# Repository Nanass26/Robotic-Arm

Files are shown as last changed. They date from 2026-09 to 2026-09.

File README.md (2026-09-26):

# ORION-6 — bras robotique 6 axes imprimé en 3D, avec son logiciel ORION Studio

<p align="center">
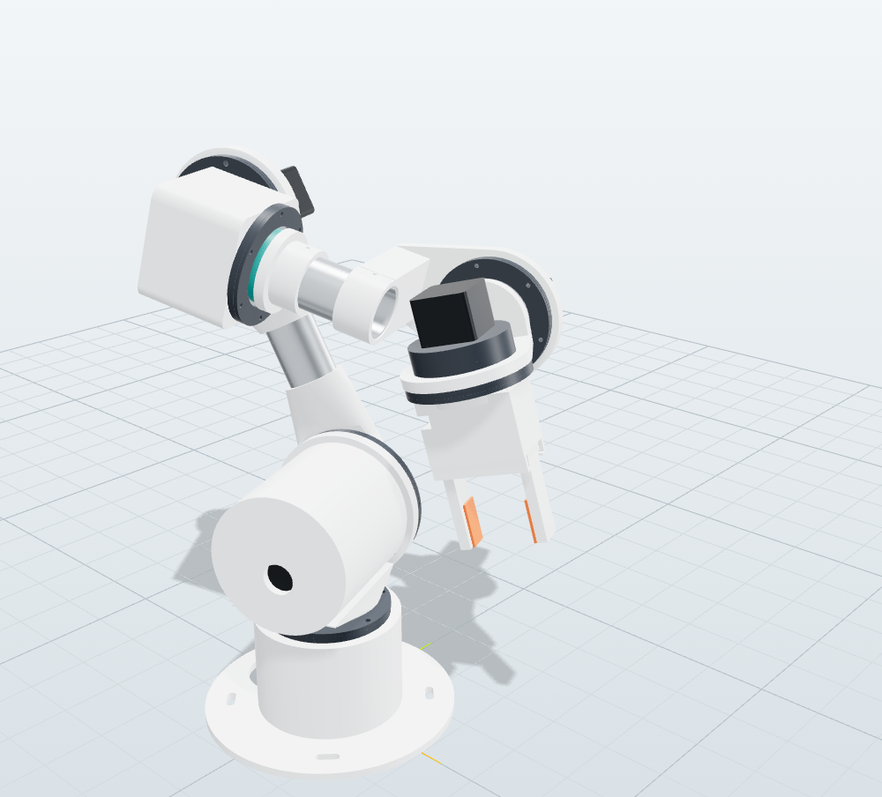
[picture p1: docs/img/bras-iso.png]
Rendu 3D du bras ORION-6 : socle, épaule, bras en tube aluminium, coude, poignet et pince
  
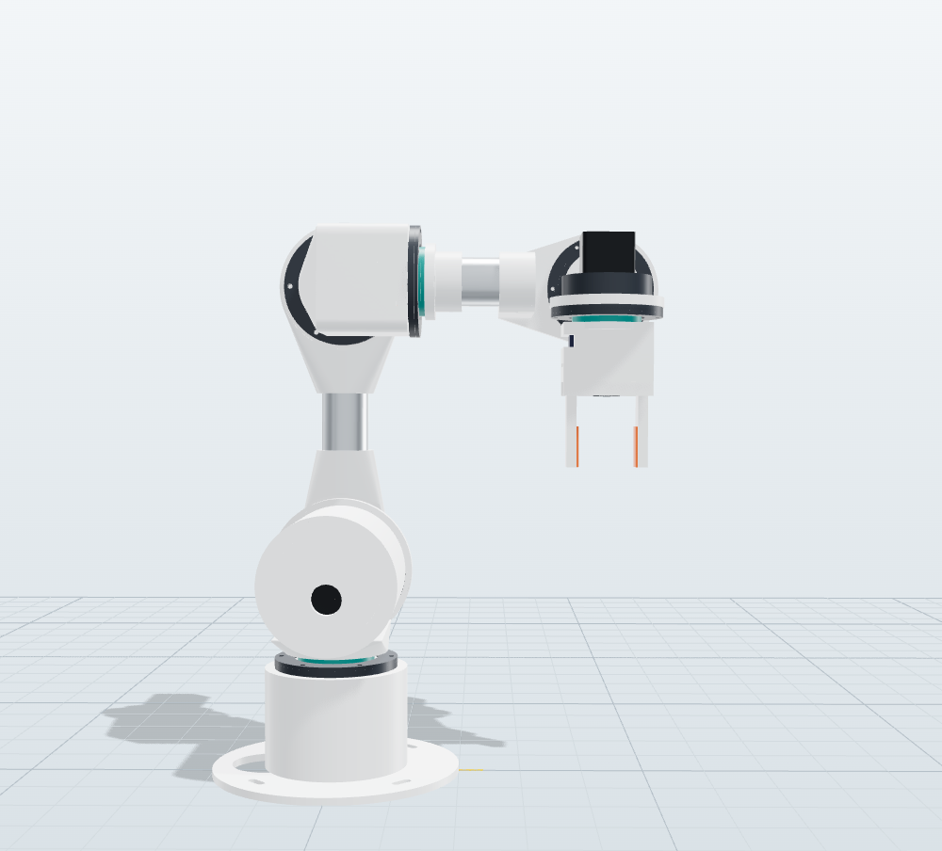
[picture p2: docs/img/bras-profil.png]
Vue de profil du bras ORION-6 en pose Home
  
</p>

**ORION-6** est un bras robotique 6 axes à imprimer en 3D, pensé comme un bras « de laboratoire ». Le dépôt contient tout
le nécessaire :

- **ORION Studio**, un logiciel de simulation et de pilotage (navigateur, hors ligne) : vue 3D, pilotage articulaire et
  cartésien, programmes, assistant en langage naturel, analyse et courbes. **Tous les paramètres** du robot y sont réglables
  en direct : géométrie, masses, moteurs, réducteurs, gains PID et **mode MIT**, trajectoires, sécurité, brochage.
- La **CAO paramétrique** et les **37 fichiers STL** prêts à imprimer. Les réducteurs cycloïdaux sont imprimés, la pince
  est à crémaillère. Le dépôt fournit aussi la nomenclature chiffrée et des contrôles automatiques : interférences,
  débattements, taille du plateau.
- Deux **firmwares Teensy 4.1** testés :
  - le contrôleur **pas-à-pas** de la version MAKER ;
  - le **pont CAN « mode MIT »** de la version PRO, pour moteurs brushless QDD de type Damiao DM4340/DM4310.
- La **documentation en français** : théorie, réglages, impression, câblage, assemblage, calibration, protocole et
  dépannage.

> ⚠️ **Prototype non validé physiquement.** La conception a été vérifiée par calcul et simulation : cinématique, dynamique,
> dimensionnement, engrènement des cycloïdes, interférences CAO et tests du firmware sur PC. Aucun exemplaire n’a encore été
> imprimé ni assemblé. Commencez par le **test de tolérances** (`hardware/stl/tolerance-test.stl`) et un module réducteur
> seul. Un bras motorisé peut blesser : prévoyez un **arrêt d’urgence qui coupe la puissance**, voir
> [docs/09-electronique.md](docs/09-electronique.md).

## Aperçu d’ORION Studio

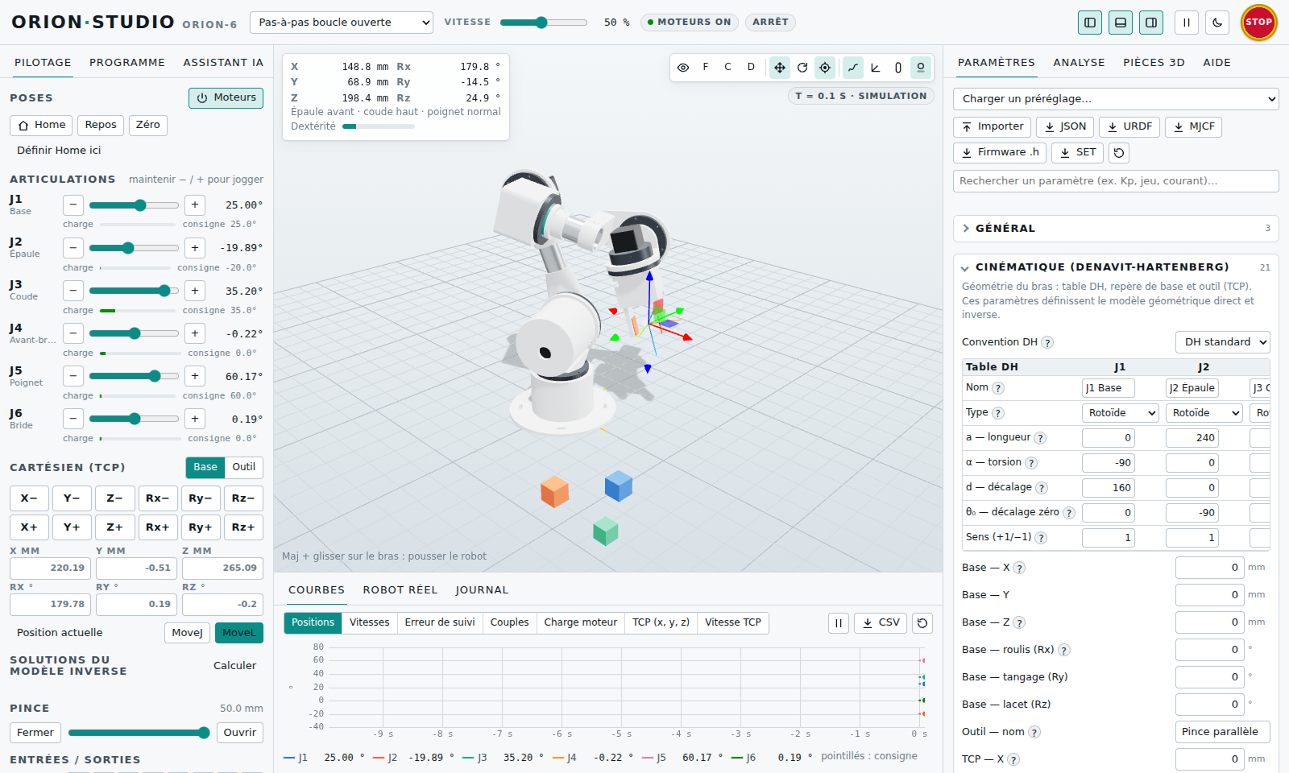
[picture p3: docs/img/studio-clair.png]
ORION Studio : pilotage à gauche, vue 3D au centre, paramètres à droite, courbes en bas


| Programme + courbes | Analyse (dimensionnement, espace de travail) | Thème sombre |
|---|---|---|
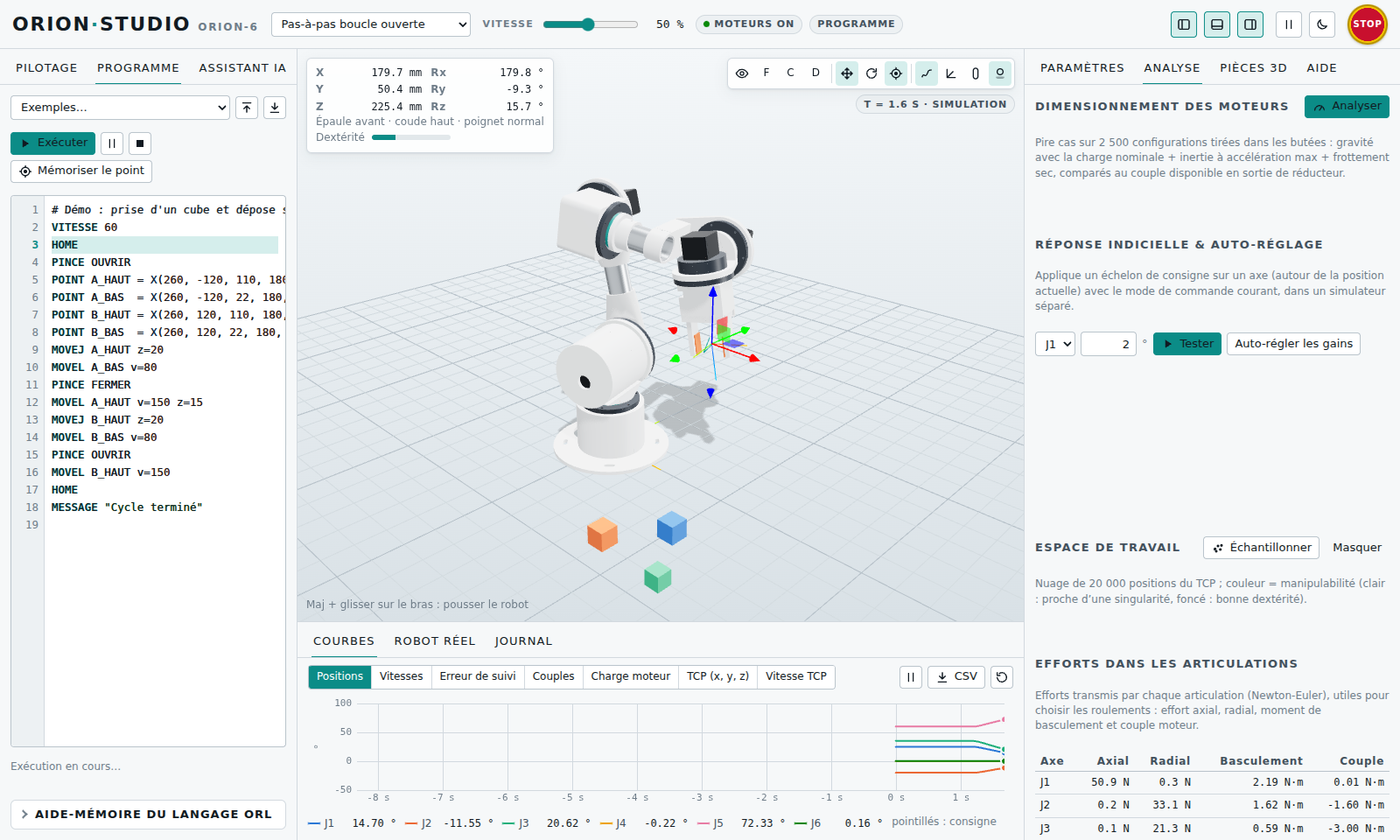
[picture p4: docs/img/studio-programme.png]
Éditeur de programme ORL en cours d’exécution
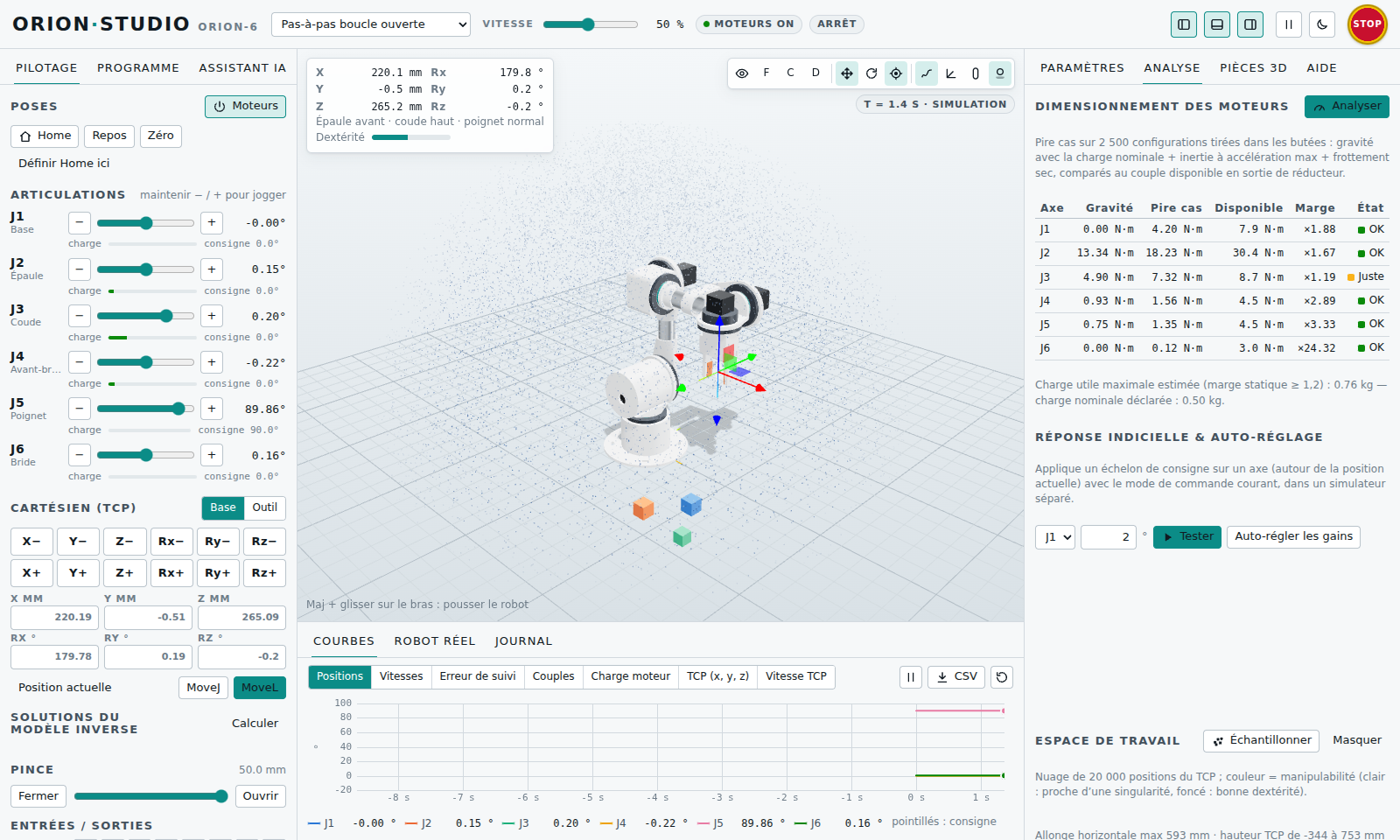
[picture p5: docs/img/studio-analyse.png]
Tableau de dimensionnement des moteurs et nuage de l’espace de travail
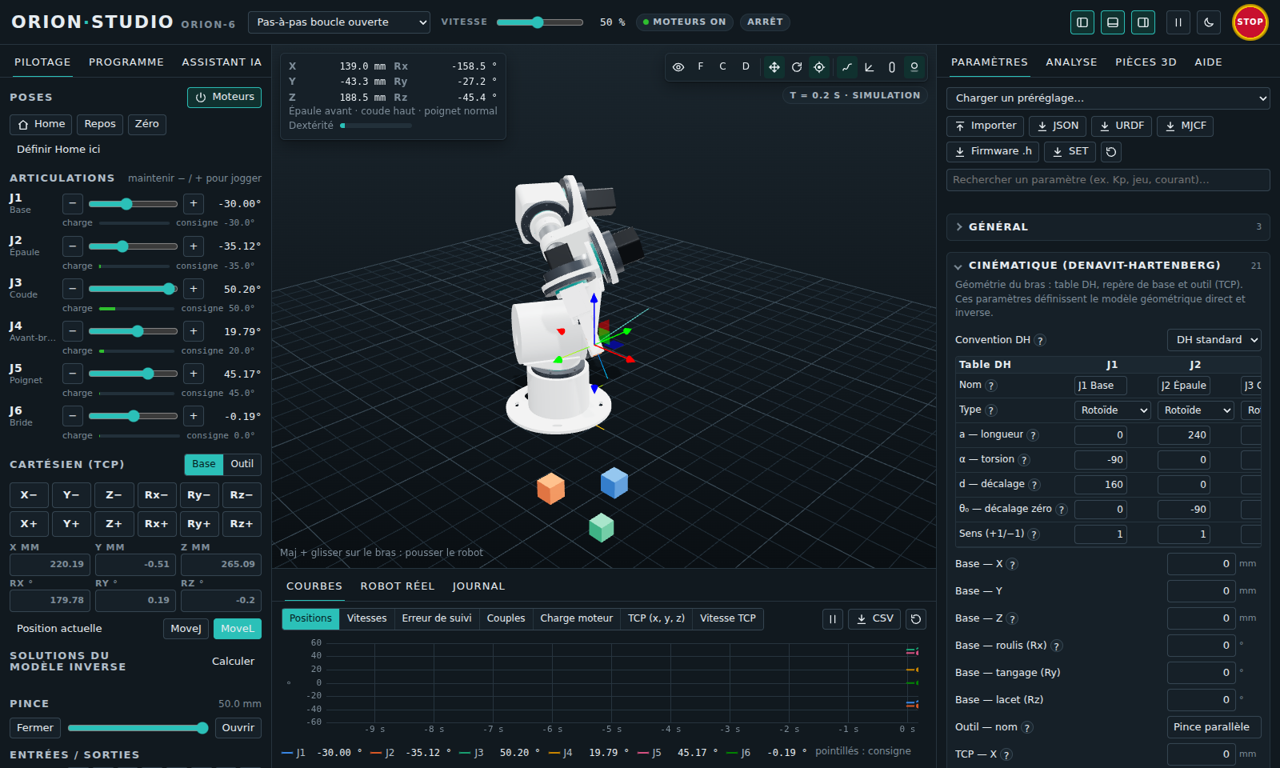
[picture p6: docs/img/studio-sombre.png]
Interface en thème sombre, onglet Paramètres
|  |  |  |

## Démarrage rapide

**Option 1 : sans rien installer.** Ouvrez `dist/ORION-Studio.html` dans Chrome, Edge ou Firefox. Ce fichier unique
fonctionne hors ligne ; il est produit par `npm run build:app`.

**Option 2 : depuis les sources.** Il faut Node.js ≥ 20.

```bash
npm install
npm start            # serveur local → http://localhost:8080/studio/
```

Ensuite, dans le logiciel :

1. Onglet **Programme** : chargez l’exemple *Prise et dépose*, puis **Exécuter**.
2. Onglet **Pilotage** : maintenez `−`/`+` pour bouger un axe. Vous pouvez aussi faire glisser le gizmo dans la vue 3D.
3. Onglet **Assistant IA** : tapez par exemple « monte de 5 cm puis ouvre la pince ».
4. Onglet **Paramètres** : modifiez n’importe quel réglage (par exemple *Kp*, *jeu*, *courant*). Le champ de recherche
   filtre la liste.

Pour piloter le **robot réel**, flashez la Teensy avec `firmware/bin/orion_fw-teensy41.hex`. Ouvrez ensuite l’onglet
**Robot réel** (Chrome/Edge sur ordinateur) et suivez [docs/11-firmware-protocole.md](docs/11-firmware-protocole.md).

## Caractéristiques (ORION-6 MAKER)

| | |
|---|---|
| Axes | 6 rotoïdes, poignet sphérique (modèle inverse analytique, 8 solutions) |
| Portée | 593 mm (horizontale, au point outil) ; 460 mm au centre du poignet |
| Hauteur de l’épaule | 160 mm ; point outil de −344 à +753 mm |
| Charge | 0,5 kg nominale ; environ 0,76 kg au maximum statique (marge 1,2) |
| Masse | ≈ 5,2 kg de parties mobiles (moteurs compris) + socle |
| Actionneurs | NEMA17/NEMA23 pas-à-pas + réducteurs **cycloïdaux imprimés** 20:1 à 30:1 |
| Vitesses max | 120 · 90 · 110 · 170 · 170 · 200 °/s (J1 → J6) |
| Commande | Teensy 4.1, drivers DM542T (ou TMC), génération de pas à 100 kHz, capteurs à effet Hall |
| Pince | parallèle à crémaillère, course 50 mm, servo MG996R, patins TPU |
| Impression | 37 STL, 58 pièces, ≈ 2,2 kg de PETG, plateau 220 × 220 × 250 mm |
| Coût matériel | ≈ 581 € ([nomenclature](docs/08-nomenclature.md)) |

La variante **ORION-6 PRO** remplace les pas-à-pas par des moteurs QDD **DM4340** (J1–J3) et **DM4310** (J4–J6). Elle est
commandée en **mode MIT** sur bus CAN : τ = Kp·(p* − p) + Kd·(v* − v) + τff, avec compensation de gravité, dans l’esprit
des bras de recherche YAM. Elle est complète côté simulation, réglage et firmware. Les brides d’adaptation imprimées pour
ces moteurs restent à dessiner.

## Organisation du dépôt

```
studio/            ORION Studio (HTML/JS, sans framework) — ouvrir studio/index.html via npm start
  core/            calculs : cinématique, dynamique, actionneurs, commande, trajectoires, simulateur,
                   langage ORL, assistant, protocoles, exports URDF/MJCF/firmware, schéma des paramètres
  ui/              interface : vue 3D (three.js), panneaux, courbes, liaison série (Web Serial)
  cad/             CAO paramétrique (manifold-3d) : réducteurs cycloïdaux, structure, pince
hardware/          STL imprimables, nomenclature (bom.csv), métadonnées des pièces (parts.json)
firmware/
  orion_fw/        firmware du contrôleur pas-à-pas (Teensy 4.1)
  mit_bridge/      firmware du pont USB ↔ CAN mode MIT (Teensy 4.1)
  test/            tests natifs sur PC (faux matériel, moteurs simulés)
  bin/             fichiers .hex prêts à flasher
docs/              documentation (français)
tools/             génération CAO/STL, documentation, configuration firmware, compilation
tests/             tests automatiques du cœur de calcul (node --test)
```

## Documentation

| | |
|---|---|
| [1. Présentation et choix de conception](docs/01-presentation.md) | le robot, les deux variantes, pourquoi des cycloïdes imprimées et le mode MIT |
| [2. Guide d’ORION Studio](docs/02-orion-studio.md) | interface, pilotage, programmes ORL, assistant, analyse, exports |
| [3. Référence de tous les paramètres](docs/03-parametres.md) | 179 paramètres, unités, plages, valeurs par défaut (généré) |
| [4. Cinématique](docs/04-cinematique.md) | table DH, modèles direct et inverse, singularités, espace de travail |
| [5. Dynamique et actionneurs](docs/05-dynamique.md) | Newton-Euler, frottements, articulation flexible, perte de pas |
| [6. Commande et réglage](docs/06-commande-et-reglage.md) | PID, **mode MIT**, couple calculé, impédance, trajectoires, méthode de réglage |
| [7. Impression 3D](docs/07-impression-3d.md) | réglages, orientation, liste des pièces (généré) |
| [8. Nomenclature](docs/08-nomenclature.md) | achats chiffrés (généré) |
| [9. Électronique et câblage](docs/09-electronique.md) | Teensy, drivers, alimentation, arrêt d’urgence, capteurs, bus CAN |
| [10. Assemblage](docs/10-assemblage.md) | réducteurs, structure, pince, passage des câbles |
| [11. Firmware et protocole](docs/11-firmware-protocole.md) | compilation, flashage, commandes série, flux temps réel, pont MIT |
| [12. Calibration et mise en service](docs/12-calibration.md) | sens, pas/°, prise d’origine, zéros, compensation de gravité |
| [13. Dépannage](docs/13-depannage.md) | symptômes → causes → remèdes |
| [14. Sources et inspirations](docs/14-sources.md) | références techniques et projets qui ont inspiré ORION-6 |

## Commandes utiles

| Commande | Rôle |
|---|---|
| `npm start` | lance ORION Studio en local (http://localhost:8080/studio/) |
| `npm test` | tests du cœur de calcul (cinématique, dynamique, programmes, exports, CAO) |
| `npm run test:firmware` | tests natifs des deux firmwares (g++/clang++, sans carte) |
| `npm run build:cad` | régénère la CAO : STL, nomenclature, masses et inerties, capsules de collision |
| `npm run build:docs` | régénère les pages de documentation générées (paramètres, pièces, nomenclature) |
| `npm run build:firmware-config` | régénère les `orion_config.h` à partir des préréglages |
| `npm run build:firmware` | compile les deux firmwares pour Teensy 4.1 (`firmware/bin/*.hex`) |
| `npm run build:app` | produit `dist/ORION-Studio.html`, un fichier unique hors ligne |

## Inspirations

ORION-6 s’inspire des bras de recherche **à moteurs brushless pilotés en mode MIT avec compensation de gravité**. Ce sont
les bras YAM d’i2rt, utilisés pour la démonstration robotique de **GPT-6 Astra** (OpenAI). Il s’inspire aussi des
nombreux bras imprimés présentés sur YouTube : AR4, Moveo, Thor, Dummy, SO-100/LeRobot. La chaîne **Defend Intelligence**
en montre un dans sa vidéo « Création bras Robot qui apprend ». Détails et liens :
[docs/14-sources.md](docs/14-sources.md).

## Licence

Aucune licence n’est encore choisie pour le code et les fichiers de ce dépôt. C’est à l’auteur du dépôt d’en décider (par
exemple MIT pour le logiciel et CERN-OHL-P pour le matériel). Les bibliothèques incluses conservent leur propre licence :
three.js (MIT) et manifold-3d (Apache-2.0), voir `studio/vendor/*/LICENSE`.

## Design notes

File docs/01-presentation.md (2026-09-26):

# 1. Présentation et choix de conception

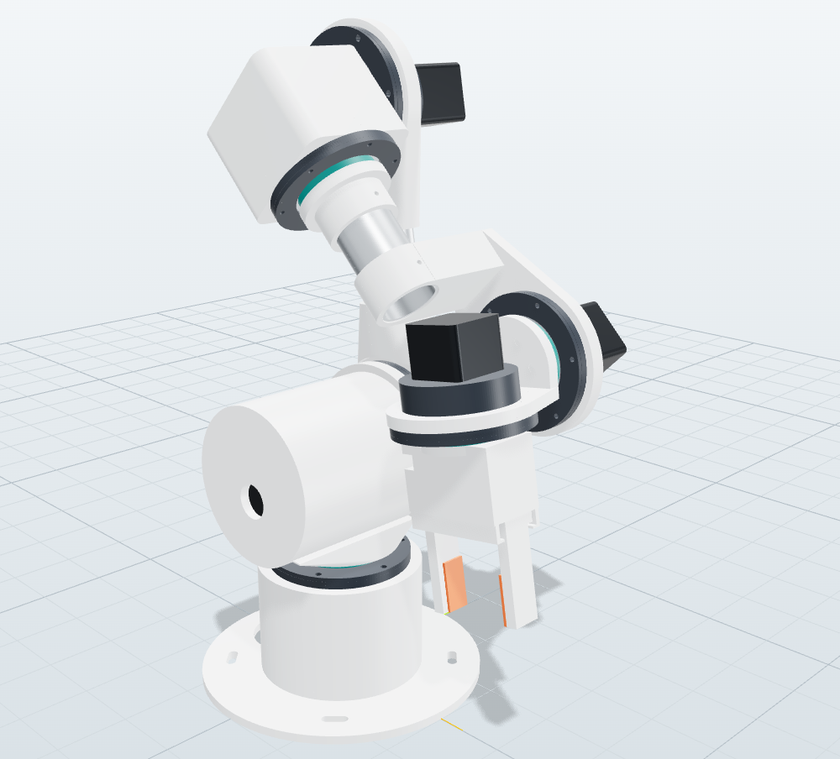
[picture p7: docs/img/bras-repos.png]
ORION-6 en pose de repos


## Le robot en bref

ORION-6 est un bras **anthropomorphe à 6 axes rotoïdes** : base, épaule, coude, puis un **poignet sphérique**
(trois axes concourants). Ce choix de géométrie, celui de la plupart des bras industriels, apporte trois avantages :

- **modèle inverse analytique** : les 8 solutions sont calculées exactement, en quelques microsecondes, sans itération
  ni blocage ;
- **découplage position / orientation** : les trois premiers axes placent le centre du poignet, les trois derniers
  orientent l’outil ;
- **programmation intuitive** : les mouvements cartésiens (MoveL, MoveC) restent prévisibles.

| Articulation | Rôle | Débattement | Réducteur | Moteur (MAKER) |
|---|---|---|---|---|
| J1 | base (lacet) | ±170° | cycloïdal CY-M 25:1 | NEMA17 48 mm |
| J2 | épaule | ±130° | cycloïdal CY-L 30:1 | NEMA23 76 mm |
| J3 | coude | −170° … +60° | cycloïdal CY-M 25:1 | NEMA17 60 mm |
| J4 | rotation d’avant-bras | ±170° | cycloïdal CY-S 20:1 | NEMA17 40 mm |
| J5 | poignet (tangage) | ±115° | cycloïdal CY-S 20:1 | NEMA17 40 mm |
| J6 | bride (roulis) | ±180° | cycloïdal CY-S 20:1 | NEMA17 34 mm |

Les longueurs principales sont les suivantes (paramètres DH, voir [4. Cinématique](04-cinematique.md)) :

- épaule à 160 mm du sol ;
- bras de 240 mm ;
- avant-bras de 220 mm ;
- bride à 33,2 mm du centre du poignet ;
- point outil (TCP) à 100,3 mm de la bride.

La **portée horizontale** au point outil est de 593 mm.

## Deux variantes

### ORION-6 MAKER : pas-à-pas + cycloïdes imprimées

- Moteurs pas-à-pas standard, drivers numériques (DM542T ou TMC), **Teensy 4.1**.
- Réducteurs **cycloïdaux imprimés en PETG**, à goupilles acier. Ils offrent un bon rapport rigidité/jeu, supportent bien
  les chocs et s’impriment sans support. Chaque module intègre son roulement principal à section mince, qui reprend les
  moments de basculement.
- Commande **en boucle ouverte**, comme la plupart des bras imprimés. La précision repose sur un dimensionnement avec
  marge (onglet *Analyse*) et sur des profils de vitesse à jerk limité. Le simulateur d’ORION Studio **reproduit la perte
  de pas** : il signale un réglage trop agressif avant qu’il ne cause un décrochage sur le vrai bras.
- Budget d’environ 581 € ([nomenclature](08-nomenclature.md)).

### ORION-6 PRO : moteurs QDD en mode MIT (CAN)

- Moteurs brushless à **faible réduction** (QDD, *quasi-direct drive*) avec driver intégré : **Damiao DM4340** (40:1,
  27 N·m crête) sur J1–J3 et **DM4310** (10:1, 7 N·m crête) sur J4–J6.
- Commande en **mode MIT**, du nom du contrôleur de moteur du robot *Mini Cheetah* du MIT. Chaque moteur exécute
  lui-même, à haute fréquence, la loi
  **τ = Kp·(p* − p) + Kd·(v* − v) + τff**. L’hôte envoie la position, la vitesse et le couple d’anticipation, qui sert à
  la compensation de gravité.
- On obtient un bras **réversible et compliant** : il peut être guidé à la main (compensation de gravité seule), il amortit
  les chocs et sert à l’apprentissage par démonstration. C’est l’architecture des bras de recherche **YAM** d’i2rt : six
  axes, moteurs DM sur bus CAN, commande PD + compensation de gravité. Ce sont ces bras que pilotait **GPT-6 Astra** dans
  la démonstration robotique d’OpenAI.
- Le firmware `firmware/mit_bridge` relie l’USB et le CAN. Il lisse les consignes et surveille le bus : moteur muet,
  erreurs, température. En cas de défaut, il amortit les axes.
- Limite actuelle : la CAO fournie est celle de la version MAKER. Les **brides d’adaptation** DM4340/DM4310 sont à
  dessiner à partir des plans du fabricant. La structure (tubes, coude, poignet) reste identique.

## Pourquoi ces choix ?

**Réducteurs cycloïdaux plutôt que courroies ou planétaires imprimés.**

- Dans une cycloïde, 30 à 50 % des goupilles sont en contact en même temps. La charge se répartit donc sur beaucoup de
  surfaces, ce qui convient bien aux plastiques.
- Deux disques décalés d’un demi-lobe équilibrent les efforts radiaux.
- Le rapport (N − 1):1 s’obtient en un seul étage compact.
- L’engrènement a été vérifié numériquement : le profil est conjugué et toutes les goupilles sont en contact au jeu
  d’impression près.

**Tube aluminium Ø40 × 2 pour le bras et l’avant-bras.** Un tube du commerce est bien plus raide qu’une pièce imprimée
de même masse, et sa longueur fixe les longueurs DH : il suffit de le couper à la cote.

**Poignet compact et déporté.** J5 et J6 sont logés dans le poignet et la chape. La **masse en bout de bras** baisse ainsi
fortement, alors qu’elle dimensionne l’épaule. Le bras pèse environ 5,2 kg de parties mobiles, moteurs compris.

**Teensy 4.1.** Ce microcontrôleur Cortex-M7 à 600 MHz dispose d’un USB natif rapide. Il génère les impulsions de pas par
accumulateur DDA à **100 kHz** sur 6 axes et interpole les consignes à 1 kHz. Son contrôleur CAN intégré sert à la
variante PRO.

**Un logiciel qui fait tout, sans installation.** ORION Studio tourne dans un navigateur, hors ligne, et se distribue en
un seul fichier HTML. Il sert à la fois de simulateur physique (dynamique complète, actionneurs, frottements, jeu), de
banc de réglage (réponse indicielle, auto-réglage, dimensionnement), d’outil de programmation et de **jumeau numérique**
du robot réel : il envoie ses consignes en temps réel par USB.

## Ce que le projet vérifie automatiquement

| Vérification | Outil | Résultat actuel |
|---|---|---|
| Modèle inverse ↔ direct (300 poses aléatoires, 8 solutions) | `npm test` | erreur de position < 10⁻⁸ m |
| URDF / MJCF ≡ table DH | `npm test` | identiques |
| Conservation de l’énergie (dynamique sans frottement, 0,5 s) | `npm test` | dérive < 0,01 % |
| Programme de prise et dépose exécuté en simulation pas-à-pas | `npm test` | cube déplacé, aucun pas perdu |
| Interférences entre pièces | `npm run build:cad` | 0 |
| Débattements CAO (auto-collision) | `npm run build:cad` | J2 ±140°, J3 −180…+65°, J5 ±120° |
| Pièces dans un plateau 220 × 220 × 250 | `npm run build:cad` | toutes |
| Firmware pas-à-pas (protocole, MoveJ, prise d’origine, flux, sécurité) | `npm run test:firmware` | 126 vérifications |
| Pont MIT (trames, flux avec gravité, défauts, repères) | `npm run test:firmware` | 74 vérifications |
| Compilation Teensy 4.1 (cœur officiel, `-Wall -Wextra`) | `npm run build:firmware` | sans avertissement |

## Sécurité

- Le bras peut pincer et heurter. Travaillez d’abord **à vitesse réduite**, avec le paramètre *Vitesse réduite* à 25 % et
  le potentiomètre de vitesse d’ORION Studio.
- L’**arrêt d’urgence** doit couper physiquement la puissance des moteurs (contacteur), en plus de l’entrée lue par le
  firmware. Voir [9. Électronique](09-electronique.md).
- Moteurs coupés (ou arrêt d’urgence), un bras à pas-à-pas **peut retomber** sous son propre poids. Les réducteurs
  cycloïdaux sont partiellement réversibles. Soutenez le bras avant de couper les moteurs.
- La prise d’origine utilise des capteurs à effet Hall. Un capteur absent ou débranché est détecté : la course de
  recherche est dépassée et le firmware passe en défaut. Pour détecter aussi un fil coupé en fonctionnement, utilisez
  des interrupteurs mécaniques à contact NF en logique active haute (voir [9. Électronique](09-electronique.md)). Les
  butées logicielles sont placées en deçà des butées mécaniques.

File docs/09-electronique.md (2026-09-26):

# 9. Électronique et câblage

> ⚠️ **Sécurité électrique.** L’alimentation de puissance (36 V continu, 10 A) peut provoquer brûlures et départs de feu
> en cas de court-circuit. Montez-la dans un boîtier fermé et protégez-la par un fusible. Ne branchez ni ne débranchez
> jamais un moteur pas-à-pas **sous tension** : la surtension détruit les drivers.

## Vue d’ensemble (ORION-6 MAKER)

```
                       ┌──────────────── ARRÊT D’URGENCE (2 contacts NF, à accrochage) ─────────────┐
 Secteur 230 V         │ NF1 : en série avec la bobine du contacteur        NF2 : entrée Teensy 30 │
    │                  │                                                                            │
 [Alim 36 V 10 A] ─ F10A ─┬─[Contacteur K1]──┬── +36 V puissance → 6 drivers (DM542T)       Teensy 30 ─┤
    │ 0 V                 │   (bobine via NF1 │                                                       GND ─┘
    │                     │    + bouton Marche)├── Buck 36→6 V 5 A → servo de pince (MG996R)
    │                     │                   │
    │                     └── Buck 36→5 V 3 A (non coupé par l’AU) → Teensy VIN*, capteurs Hall, 74HCT245
    │
    └── 0 V commun (drivers : entrées logiques ; Teensy : GND)          PC ── USB ── Teensy 4.1
```

\* Si la Teensy est alimentée à la fois par l’USB et par VIN, **coupez le pont VIN-VUSB** au dos de la carte (pastille
prévue par PJRC). Sinon le 5 V externe remonte dans l’USB du PC.

- L’**arrêt d’urgence coupe la puissance des moteurs** (catégorie 0) par le contacteur K1. La logique (Teensy) reste
  alimentée et **l’entrée 30 signale l’arrêt** au firmware : les drivers sont désactivés et le robot doit être
  référencé de nouveau.
- Le réarmement demande deux actions : déverrouiller le champignon, puis appuyer sur un bouton **Marche** (auto-maintien
  du contacteur). Le robot ne redémarre jamais seul.
- ⚠️ Moteurs coupés, le bras peut **retomber** sous son poids. Avant de manipuler, amenez-le en pose de repos (*Repos*,
  bras replié) ou soutenez-le.

## Brochage de la Teensy 4.1 (firmware `orion_fw`)

Le brochage par défaut est généré dans `orion_config.h`. Il est modifiable dans *Paramètres → Matériel & firmware*,
avant de recompiler.

| Fonction | J1 | J2 | J3 | J4 | J5 | J6 |
|---|---|---|---|---|---|---|
| STEP | 2 | 4 | 6 | 8 | 10 | 12 |
| DIR | 3 | 5 | 7 | 9 | 11 | 14 |
| Capteur d’origine | 24 | 25 | 26 | 27 | 28 | 29 |

| Fonction | Broche | Remarque |
|---|---|---|
| ENABLE (commun aux 6 drivers) | 15 | actif **bas** par défaut (drivers activés quand la broche est à 0) |
| Arrêt d’urgence (entrée) | 30 | contact NF vers GND ; niveau haut = arrêt (fil coupé compris) |
| Servo de pince (MLI 50 Hz) | 33 | signal seul ; le servo est alimenté par le buck 6 V |
| Entrées TOR DI0…DI7 | 16, 17, 18, 19, 20, 21, 22, 23 | actives bas, rappel interne au 3,3 V |
| Sorties TOR DO0…DO7 | 31, 32, 34, 35, 36, 37, 38, 39 | 3,3 V, 4 mA max : passez par un transistor ou un relais |
| LED d’état | 13 | lente = prêt, rapide = mouvement, fixe = défaut, éclair toutes les 2 s = moteurs coupés |

> ⚠️ Les broches de la Teensy 4.1 sont en **3,3 V et ne tolèrent pas le 5 V**. N’y reliez jamais directement une sortie
> 5 V ou 12 V.

## Drivers pas-à-pas

### DM542T (ou équivalent optocouplé : DM556, TB6600…)

Leurs entrées sont des optocoupleurs qui demandent 5 V environ 10 mA. Les 3,3 V de la Teensy sont souvent
insuffisants et donnent des pas manqués aléatoires. **Intercalez un tampon 74HCT245** alimenté en 5 V :

```
Teensy STEP/DIR/EN (3,3 V) → 74HCT245 (VCC = 5 V, DIR = 5 V, OE = GND) → PUL+ / DIR+ / ENA+ du driver
                                                                         PUL− / DIR− / ENA− → GND commun
```

Deux 74HCT245 suffisent pour les 13 signaux (6 STEP + 6 DIR + ENABLE).

Réglages par micro-interrupteurs :

| Axe | Moteur | Courant crête conseillé | Micro-pas |
|---|---|---|---|
| J1 | NEMA17 48 mm (2,0 A) | 1,8 A (≈ 90 %) | 16 (3 200 pas/tr) |
| J2 | NEMA23 76 mm (2,8 A) | 2,5 A | 16 |
| J3 | NEMA17 60 mm (2,1 A) | 1,9 A | 16 |
| J4, J5 | NEMA17 40 mm (1,7 A) | 1,5 A | 16 |
| J6 | NEMA17 34 mm (1,3 A) | 1,2 A | 16 |

- Activez la **réduction de courant au repos** (« half current ») : elle fait moins chauffer, et le maintien reste
  largement suffisant grâce à la réduction.
- Le signal ENABLE du DM542T **désactive** le driver quand l’optocoupleur conduit. Avec le câblage ci-dessus (ENA+ piloté,
  ENA− à la masse), un niveau haut désactive, d’où « ENABLE actif bas » dans les paramètres.
- Les temps imposés (DM542T : impulsion ≥ 2,5 µs, DIR ≥ 5 µs avant le front) sont garantis par le firmware : impulsion
  de 10 µs, DIR changé au moins 10 µs après le dernier front et 20 µs avant le suivant.

### TMC2209 / TMC5160 (modules « silencieux »)

Ils acceptent directement la logique 3,3 V : pas besoin de 74HCT245. Utilisez le mode STEP/DIR. Mettez le TMC5160 sur J2
(courant élevé) et des TMC2209 (2 A efficaces max) sur les autres axes. Le couple des TMC2209 à haute vitesse est un peu
plus faible : vérifiez les marges dans *Analyse → Dimensionnement*. Ne comptez pas sur le *StallGuard* pour la prise
d’origine, peu fiable avec la réduction et le frottement des cycloïdes.

### Moteurs

- Câble blindé 4 × 0,5 mm². Reliez le blindage à la masse **côté driver uniquement**, et éloignez ces câbles de ceux des
  capteurs.
- Si un axe tourne à l’envers, inversez **une seule** bobine (A+ ↔ A−), ou cochez *Inverser DIR* dans les paramètres
  (commande `SET invert`).

## Capteurs de prise d’origine

**Capteur à effet Hall A3144** et aimant néodyme Ø6 × 3 mm collé sur la partie mobile, face sud vers le capteur :

```
A3144 : VCC ← 5 V      GND ← GND      OUT → broche 24…29 de la Teensy (collecteur ouvert,
                                             rappel interne au 3,3 V activé par le firmware)
```

- Sortie à 0 quand l’aimant est présent, d’où *Capteur actif bas* coché par défaut.
- Positions des capteurs (angle articulaire au déclenchement), à régler ensuite par calibration :

  | J1 | J2 | J3 | J4 | J5 | J6 |
  |---|---|---|---|---|---|
  | −172° | −133° | +62° | −172° | −117° | −182° |

  Elles se trouvent 2° au-delà des butées logicielles : pendant la prise d’origine, l’axe va chercher le capteur, puis
  s’en dégage et revient dans ses butées.
- Le firmware filtre les rebonds (état stable 2 ms). Il met le robot **en défaut** si un capteur s’active pendant un
  mouvement normal, ou si la course de recherche est dépassée (capteur absent ou débranché).
- **Variante « sécurité » avec interrupteurs mécaniques à contact NF** : câblez l’interrupteur entre la broche et GND
  et décochez *Capteur actif bas*. Le contact est fermé (niveau bas) au repos. Il s’ouvre (niveau haut) quand
  l’interrupteur est actionné **ou si le fil est coupé**.
- ⚠️ Beaucoup de capteurs inductifs NPN (série NJK, LJ12A3…) ont une résistance de rappel interne vers leur tension
  d’alimentation (5–30 V). Ils ne doivent **pas** être reliés directement à la Teensy : utilisez un optocoupleur ou un
  pont diviseur.

## Pince

- Servo **MG996R** alimenté en **6 V** par un buck dédié : les appels de courant (jusqu’à 2,5 A au blocage)
  perturberaient sinon la logique. Masse commune avec la Teensy.
- Signal sur la broche 33 : MLI matérielle 50 Hz. Largeurs 900 µs (fermée) à 2 100 µs (ouverte), réglables
  (`SET grip_closed`, `SET grip_open`).

## Bus CAN (ORION-6 PRO, firmware `mit_bridge`)

```
Teensy 4.1           SN65HVD230 (3,3 V)                       moteurs DM4340 / DM4310
 22 (CTX1) ──────────► D
 23 (CRX1) ◄────────── R
 3,3 V ────────────── VCC        CAN_H ═══╤═══════╤═══════ … ═══╤══ [120 Ω]
 GND ──────────────── GND        CAN_L ═══╧═══════╧═══════ … ═══╧══
                                 [120 Ω]   J1      J2            J6
```

- **Transceiver 3,3 V** (SN65HVD230 ou TJA1051T/3). Le MCP2551, alimenté en 5 V, n’est pas compatible directement.
- Paire torsadée CAN_H / CAN_L en ligne (chaînage), **terminaison 120 Ω aux deux extrémités** (60 Ω mesurés entre
  CAN_H et CAN_L, alimentation coupée). Débit 1 Mbit/s.
- Identifiants moteurs 1 à 6 (commande), réglés avec l’outil du fabricant, qui fixe aussi l’identifiant maître et les
  plages P/V/T.
- Charge du bus : chaque trame de commande reçoit une réponse. 6 moteurs à 400 Hz occupent environ 60 % d’un bus à
  1 Mbit/s. Au-delà de 500 Hz, répartissez les moteurs sur deux bus (CAN1 et CAN2 de la Teensy).
- Puissance : 24 V, 15 A minimum pour 3 × DM4340 + 3 × DM4310, avec fusible. **L’arrêt d’urgence coupe le 24 V des
  moteurs** : sans alimentation, ils redeviennent réversibles.
- Arrêt d’urgence (entrée) : broche 30, comme pour la version pas-à-pas.

## Mise sous tension : ordre conseillé

1. Contrôle visuel : polarités, pas de fil nu, blindages, fusible.
2. Alimentation 36 V **sans** les moteurs : vérifiez 36 V, puis 5 V et 6 V en sortie des bucks.
3. Teensy sur USB seule : flashez, puis vérifiez `PING` et `STAT` depuis ORION Studio.
4. Testez l’arrêt d’urgence : `STAT` doit afficher `ESTOP` (drapeau 0x10) quand le champignon est enfoncé.
5. Actionnez chaque capteur à la main (aimant) : le drapeau 0x40 apparaît dans `STAT`.
6. Branchez les moteurs **hors tension**, réarmez, puis `EN 1` : les moteurs doivent se bloquer (couple de maintien).
7. Premiers mouvements à 10 % de vitesse avec `JG` (voir [12. Calibration](12-calibration.md)).

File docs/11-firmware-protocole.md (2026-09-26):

# 11. Firmware et protocole

Deux firmwares pour **Teensy 4.1**, construits de la même façon :

- un **cœur portable** en C++, sans aucune dépendance Arduino, testé sur PC avec un faux matériel ;
- une **couche matérielle** mince (`main.cpp`).

| Firmware | Dossier | Rôle |
|---|---|---|
| `orion_fw` | `firmware/orion_fw` | contrôleur pas-à-pas d’ORION-6 MAKER : génération de pas, prise d’origine, trajectoires, flux temps réel |
| `mit_bridge` | `firmware/mit_bridge` | pont USB ↔ CAN d’ORION-6 PRO : trames mode MIT, lissage des consignes, surveillance des moteurs |

## Flasher la Teensy

**Méthode la plus simple : fichier .hex prêt à l’emploi.**

1. Installez **Teensy Loader** (PJRC) ou Teensyduino.
2. *File → Open HEX File* : `firmware/bin/orion_fw-teensy41.hex` (ou `mit_bridge-teensy41.hex`).
3. Appuyez sur le bouton de la Teensy : le chargement est automatique.

Ces fichiers contiennent la configuration par défaut. Vos réglages (pas/°, butées, vitesses, prise d’origine…) s’envoient
ensuite **sans recompiler**, par le bouton *Envoyer la config* d’ORION Studio. Il envoie des commandes `SET` puis
`SAVE`, qui enregistre en EEPROM.

**Autres méthodes :**

| Outil | Procédure |
|---|---|
| IDE Arduino + Teensyduino | ouvrir `firmware/orion_fw/orion_fw.ino`. Carte *Teensy 4.1*, USB Type *Serial*, CPU 600 MHz, puis *Téléverser* |
| PlatformIO | dans `firmware/orion_fw` : `pio run -e teensy41 -t upload` |
| Ligne de commande (GCC ARM) | `npm run build:firmware`, puis Teensy Loader sur `firmware/bin/*.hex` |

Pour recompiler avec **votre** configuration par défaut : *Paramètres → Firmware .h* dans ORION Studio. Remplacez
`firmware/orion_fw/src/orion_config.h` par le fichier obtenu, puis recompilez.

**Tests sur PC** (aucune carte nécessaire) : `npm run test:firmware`, soit 126 vérifications pour `orion_fw` et 74 pour
`mit_bridge`. Le faux matériel simule :

- les drivers, avec contrôle des temps DIR/STEP ;
- les capteurs d’origine et l’arrêt d’urgence ;
- l’EEPROM ;
- six moteurs Damiao sur un faux bus CAN.

Ces tests couvrent le protocole, MoveJ, la prise d’origine avec position inconnue, le flux à 60 Hz irrégulier, les
sauts de consigne, le chien de garde, les défauts et la sauvegarde.

## Protocole ORION-ASCII (commun aux deux firmwares)

- Liaison **USB série** native de la Teensy. La vitesse est ignorée : n’importe quelle valeur convient, 115 200 par
  exemple.
- **Une commande par ligne**, terminée par `\n`. La casse du mot-clé est libre.
- **Somme de contrôle optionnelle** `*HH` en fin de ligne : XOR de tous les caractères qui précèdent `*`, en
  hexadécimal.
  - Une somme fausse donne `ERR 1`.
  - ORION Studio l’ajoute toujours ; à la main, on peut l’omettre.
- **Toutes les réponses** portent une somme de contrôle :

| Réponse | Forme | Sens |
|---|---|---|
| `OK …` | `OK PONG ORION-6 fw1.0.0 axes=6*78` | commande acceptée (+ données éventuelles) |
| `ERR code message` | `ERR 5 J2 hors butees (150.00)*25` | commande refusée |
| `EVT nom …` | `EVT DONE*67` | événement asynchrone |
| `ST …` | `ST HOLD 18342 0.000 0.000 0.000 0.000 90.000 0.000 03 00*0E` | état périodique |

Exemple de calcul : pour `PING`, 'P' ⊕ 'I' ⊕ 'N' ⊕ 'G' = 0x50 ⊕ 0x49 ⊕ 0x4E ⊕ 0x47 = 0x10, soit `PING*10`.

### Codes d’erreur

| Code | Sens |
|---|---|
| 1 | somme de contrôle incorrecte |
| 2 | commande inconnue |
| 3 | syntaxe ou argument invalide (nombre d’arguments, valeur hors plage, ligne trop longue) |
| 4 | commande interdite dans l’état actuel (moteurs coupés, défaut, prise d’origine requise, robot en mouvement) |
| 5 | consigne hors butées, ou début de flux trop éloigné de la position actuelle |
| 6 | (pont MIT) moteur muet sur le bus CAN |
| 7 | arrêt d’urgence actif |
| 8 | EEPROM indisponible ou configuration invalide |

### Ligne d’état `ST`

```
ST <état> <t_ms> <q1> … <q6> <drapeaux hex> <entrées hex>
```

- Les positions `q` sont en **degrés** articulaires. Pour `orion_fw`, ce sont les pas réellement émis, convertis en
  degrés. Pour `mit_bridge`, ce sont les positions mesurées par les codeurs.
- La fréquence d’envoi se règle avec `STREAM hz` (0 = arrêt, 500 max). `STAT` demande une ligne ponctuelle.

| Drapeau | Bit | Sens |
|---|---|---|
| enabled | 0x01 | drivers / moteurs actifs |
| homed | 0x02 | robot référencé |
| moving | 0x04 | mouvement en cours |
| fault | 0x08 | défaut (voir `FLT`) |
| estopInput | 0x10 | entrée d’arrêt d’urgence active |
| watchdog | 0x20 | le chien de garde du flux a déclenché |
| limit | 0x40 | un capteur de fin de course est actif (pont MIT : axe hors butées) |
| underrun | 0x80 | le tampon de flux s’est vidé (consignes en retard) |
| limited | 0x100 | le limiteur vitesse/accélération a écrêté la consigne |

### États

| État | Sens | Pour en sortir |
|---|---|---|
| `IDLE` | drivers coupés | `EN 1` |
| `READY` | drivers actifs, **non référencé** | `HOME` ou `ZERO` (ou `JG` pour de petits déplacements) |
| `HOMING` | prise d’origine en cours | fin automatique → `HOLD`, ou `STOP` |
| `RUN` | mouvement (`MJ`, `JG`, flux `SP`) | fin → `HOLD`, `STOP` → arrêt contrôlé |
| `HOLD` | référencé, à l’arrêt, prêt | `MJ`, `SP`, `JG`, `HOME`… |
| `FAULT` | défaut (capteur atteint, prise d’origine échouée…) | `CLR` |
| `ESTOP` | arrêt d’urgence (entrée ou commande `ESTOP`) | relâcher l’AU, `CLR`, `EN 1`, `HOME` |

Couper les drivers (`EN 0`, arrêt d’urgence) **fait perdre la référence**. Moteurs libres, la position n’est plus
garantie.

## Commandes du firmware pas-à-pas (`orion_fw`)

| Commande | Effet | Réponse |
|---|---|---|
| `PING` | identification | `OK PONG ORION-6 fw1.0.0 axes=6` |
| `VER` | version | `OK VER 1.0.0` |
| `STAT` | une ligne d’état | `ST …` |
| `STREAM hz` | lignes `ST` périodiques (0 = arrêt) | `OK STREAM 50` |
| `FLT` | dernier message de défaut | `OK FLT fin de course J3` |
| `EN 1` / `EN 0` | active / coupe les drivers | `OK EN 1` |
| `HOME [masque]` | prise d’origine (masque optionnel, bit 0 = J1 : `HOME 0x3F` = tous) | `OK HOME 0x3F`, puis `EVT HOMED_AXIS n`…, `EVT HOMED`, `EVT DONE` |
| `ZERO` | déclare la position actuelle comme **pose Home** (sans capteurs) | `OK ZERO` |
| `JG axe delta` | déplacement relatif d’un axe (°, \|delta\| ≤ 30), possible sans référence | `OK MJ durée`, puis `EVT DONE` |
| `MJ T q1 … q6` | MoveJ vers q (°), durée T (s) ; T = 0 → au plus vite | `OK MJ durée`, puis `EVT DONE` |
| `SP seq t q1 … q6 [v1 … v6]` | consigne du **flux temps réel** (voir plus bas) | aucune (sauf erreur) |
| `STOP` | arrêt contrôlé (décélération max) | `OK STOP`, puis `EVT STOPPED` |
| `ESTOP` | arrêt d’urgence logiciel : drivers coupés | `OK ESTOP` |
| `CLR` | acquitte un défaut ou un arrêt d’urgence (entrée relâchée) | `OK CLR` |
| `GRIP pct` | pince : 0 = fermée, 100 = ouverte | `OK GRIP 50` |
| `DO n v` | sortie TOR n (0–7) à v (0/1) | `OK DO 3 1` |
| `DI` | lecture des 8 entrées (hex) | `OK DI 42` |
| `SET clé axe valeur` | règle un paramètre (axe 1–6 ou `*`) | `OK SET vmax 2 45` |
| `GET clé axe` | lit un paramètre | `OK 45` |
| `SAVE` / `LOAD` / `DEFAULTS` | EEPROM : enregistrer / recharger / valeurs d’usine | `OK SAVE` |

### Paramètres `SET` / `GET` (`orion_fw`)

| Clé | Unité | Rôle |
|---|---|---|
| `steps_per_deg` | pas/° | (360/angle de pas) × micro-pas × réduction / 360. Le changement conserve la position angulaire |
| `min`, `max` | ° | butées logicielles |
| `vmax`, `amax` | °/s, °/s² | limites de vitesse et d’accélération |
| `invert` | 0/1 | inversion du sens (câblage) |
| `home_dir` | −1/+1 | sens de recherche du capteur |
| `home_pos` | ° | angle articulaire au déclenchement du capteur (calibration) |
| `home_speed`, `home_slow` | °/s | vitesse de recherche rapide, puis d’approche fine |
| `home_backoff` | ° | dégagement après détection |
| `home_pose` | ° | pose atteinte après la prise d’origine, et pose déclarée par `ZERO` |
| `home_en` | 0/1 | axe équipé d’un capteur |
| `watchdog` (`*`) | ms | chien de garde du flux (défaut 250) |
| `stream_delay` (`*`) | ms | retard du tampon de lissage (défaut 40) |
| `grip_closed`, `grip_open` (`*`) | µs | impulsions servo fermée / ouverte |

### Mouvement

- **Génération de pas** : accumulateur de phase (DDA) à **100 kHz**, 45 000 pas/s max par axe. Impulsion STEP de
  10 µs. Le changement de DIR est appliqué entre deux impulsions : ≥ 10 µs après le dernier front, ≥ 20 µs avant le
  suivant.
- **Boucle 1 kHz** : calcule la consigne de chaque axe puis la vitesse de pas nécessaire pour l’atteindre en 1 ms.
- **MoveJ (`MJ`)** : profil trapézoïdal synchronisé (25 % accélération, 50 % vitesse constante, 25 % décélération).
  Durée = max(T, max_axes(Δ/(0,75·vmax), √(Δ/(0,1875·amax)))). Tous les axes arrivent ensemble.
- **Limiteur de sécurité** : toute consigne passe par un limiteur de vitesse (1,05·vmax) et d’accélération (1,5·amax).
  Le rattrapage est borné par la distance de freinage (v ≤ √(2·a·écart)). Un saut de consigne est donc rejoint **sans
  dépassement**, ce que vérifie un test avec un saut de 60°.
- **Butées** : les consignes sont écrêtées aux butées logicielles dès que le robot est référencé. `MJ` hors butées est
  refusé (`ERR 5`).

### Flux temps réel `SP` (jumeau numérique)

```
SP <seq> <t_ms> <q1> … <q6> [<v1> … <v6>]
```

- `seq` : numéro de séquence sur 16 bits, qui reboucle. Les doublons et les consignes périmées sont ignorés.
- `t_ms` : horodatage de l’**émetteur** en millisecondes, sur 16 bits, qui reboucle.
- `q` en degrés, `v` en °/s (facultatives).

Le firmware ne suppose **aucune cadence fixe** :

1. Les consignes sont rangées dans un tampon (32 places) avec leur horodatage d’origine.
2. La lecture démarre quand le tampon contient `stream_delay` ms d’avance (40 ms par défaut).
3. L’horloge de lecture avance de 1 ms par ms, avec une correction lente (±5 % au plus) pour garder cette avance
   constante. Elle absorbe la gigue de l’USB et du navigateur, ainsi que la dérive des horloges.
4. Entre deux consignes, l’interpolation est **cubique d’Hermite** si les vitesses sont fournies, linéaire sinon.
5. **Démarrage** : la première consigne doit être à moins de 5° de la consigne actuelle (`ERR 5` sinon). Utilisez
   *Synchroniser* dans ORION Studio, ou un `MJ` préalable.
6. **Chien de garde** : sans nouvelle consigne pendant `watchdog` ms, le firmware émet `EVT WATCHDOG` puis s’arrête en
   douceur (`EVT STOPPED`).

Sur le banc de test (émission à 55–67 Hz, gigue d’arrivée de 0 à 8 ms, sinusoïdes de 25° d’amplitude), l’erreur
maximale mesurée entre la position réelle et la trajectoire émise, retardée du tampon, est de **0,52°**.

### Prise d’origine (`HOME`)

Les axes sont référencés un par un, dans l’ordre configuré : par défaut **J5, J6, J4, J3, J2, J1**. On replie d’abord
le poignet pour réduire l’encombrement. Pour chaque axe :

1. S’il est déjà sur son capteur, il s’en dégage (`home_backoff`).
2. **Approche rapide** vers le capteur (`home_speed`, sens `home_dir`).
3. **Recul** de `home_backoff` jusqu’à libérer le capteur.
4. **Approche lente** (`home_slow`) : au front du capteur, la position de l’axe devient `home_pos`.
5. **Dégagement** de `home_backoff`, pour revenir dans les butées et libérer le capteur.

Quand tous les axes sont faits : `EVT HOMED`, puis MoveJ vers `home_pose` et `EVT DONE`.

Défauts possibles :

- capteur introuvable (course > débattement + 20°) ;
- capteur bloqué (> 45° sans libération) ;
- capteur perdu pendant l’approche lente.

La répétabilité dépend de l’approche lente : à 2°/s, avec un anti-rebond de 2 ms, l’incertitude est d’environ 0,004°
à la sortie.

### Sécurité

- **Entrée d’arrêt d’urgence** (broche 30) : lue à chaque milliseconde, avec 2 ms d’anti-rebond. Elle coupe les
  drivers, passe en `ESTOP` et émet `EVT ESTOP`. La référence est perdue.
- **Capteur de fin de course actif** pendant `RUN` ou `HOLD` : arrêt immédiat, `EVT FAULT fin de course Jn`.
- **Ligne trop longue** (> 199 caractères) : ignorée, avec `ERR 3`.
- **Configuration EEPROM** protégée par un CRC32 et un numéro de version. Une configuration corrompue est ignorée au
  démarrage, qui reprend alors les valeurs par défaut.
- **Écriture série non bloquante** : si l’hôte ne lit pas, les lignes sont abandonnées, sans jamais bloquer la boucle
  temps réel.

### Exemple de session

```text
> PING                         < OK PONG ORION-6 fw1.0.0 axes=6
> EN 1                         < OK EN 1
> HOME                         < OK HOME 0x3F
                               < EVT HOMED_AXIS 5 … EVT HOMED_AXIS 1
                               < EVT HOMED
                               < OK MJ 1.912
                               < EVT DONE
> MJ 2 30 -20 40 0 70 0        < OK MJ 2.000
                               < EVT DONE
> GRIP 0                       < OK GRIP 0
> STAT                         < ST HOLD 61234 30.000 -20.000 40.000 0.000 70.000 0.000 03 00
```

## Pont CAN mode MIT (`mit_bridge`)

Le pont relie ORION Studio, ou tout programme de pilotage, aux six moteurs QDD. Il envoie une trame MIT par moteur à
`ctrl_hz` (400 Hz par défaut) et reçoit les retours : position, vitesse, couple, températures, code d’erreur. Les
positions échangées avec l’hôte sont **articulaires, en degrés**. La conversion vers le repère de chaque moteur se fait
dans le pont : p_moteur = sens·(q − décalage), en radians.

| Commande | Effet |
|---|---|
| `PING`, `VER`, `STAT`, `FLT`, `STREAM hz` | comme `orion_fw` (les lignes `ST` contiennent les positions **mesurées**) |
| `FB` | retours détaillés : `OK FB v/τ/T_mos/T_rotor/err` pour chaque axe (°/s, N·m, °C) |
| `EN 1` | active les moteurs (trame 0xFC) et **maintient** la position mesurée (Kp, Kd, τ = 0). Refusé si un moteur n’a pas répondu (`ERR 6`) |
| `EN 0` | **amortissement** pendant 1,5 s (Kp = 0, Kd = `kd_damp`), puis coupure (0xFD) |
| `DAMP` | amortissement maintenu (le bras se laisse déplacer lentement) |
| `MC seq t q1…q6 [v1…v6 [τ1…τ6]]` | flux de consignes : positions (°), vitesses (°/s), couples d’anticipation (N·m) |
| `STOP` | fige la dernière consigne (maintien avec le dernier couple d’anticipation) |
| `ESTOP` | coupure immédiate des moteurs (0xFD) |
| `CLR` | efface les erreurs moteur (0xFB). Défaut → maintien de la position actuelle ; arrêt d’urgence → `IDLE` |
| `ZERO` | la position actuelle devient la **pose de référence** `ref_pose` (pose de repos par défaut). Calcule les décalages logiciels ; `SAVE` pour les garder |
| `MZERO masque` | écrit le zéro dans les moteurs (0xFE), moteurs coupés uniquement |
| `SET`/`GET`/`SAVE`/`LOAD`/`DEFAULTS` | paramètres (ci-dessous) |

**Comportement** :

- **Moteurs coupés** (`IDLE`) : le pont interroge les moteurs à 50 Hz par des trames à gains et couple nuls. Les
  positions restent donc lisibles, en *Miroir* dans ORION Studio par exemple.
- **Démarrage du flux** : la première consigne doit être à moins de 5° de la position mesurée. Un **raccord de 300 ms**
  fait passer en douceur la position et le couple du maintien au flux, sans à-coup de gravité.
- **Lissage** : même tampon horodaté et même interpolation d’Hermite que `orion_fw`. La vitesse envoyée au moteur est la
  dérivée de l’interpolant. Le couple d’anticipation est interpolé linéairement.
- **Chien de garde** (`watchdog`, 250 ms par défaut) : maintien sur la dernière consigne **avec le dernier couple de
  gravité**. Le bras reste en place au lieu de retomber.
- **Défauts → amortissement** (Kp = 0, Kd = `kd_damp`, dernier couple d’anticipation conservé). Ils sont déclenchés
  par :
  - un moteur muet depuis plus de `fb_timeout` ms ;
  - un code d’erreur moteur : surtension, sous-tension, surintensité, surchauffe MOSFET ou bobinage, perte de
    communication, surcharge ;
  - une température ≥ `max_temp` ;
  - une position hors butées de plus de 5°.
- **Bornes** : consignes écrêtées aux butées, vitesse bornée à `vmax`, couple d’anticipation borné à `tau_max`.

| Clé `SET` | Unité | Rôle |
|---|---|---|
| `kp`, `kd` | N·m/rad, N·m·s/rad | gains MIT, limités à `kp_max` / `kd_max` |
| `kd_damp` | N·m·s/rad | amortissement en défaut ou arrêt |
| `dir`, `offset` | ±1, ° | repère : q = dir·p_moteur + offset (moteurs coupés) |
| `min`, `max`, `vmax`, `tau_max` | °, °/s, N·m | bornes |
| `ref_pose` | ° | pose déclarée par `ZERO` |
| `can_id` | — | identifiant CAN du moteur (moteurs coupés) |
| `p_max`, `v_max`, `t_max`, `kp_max`, `kd_max` | rad, rad/s, N·m… | plages d’encodage des trames, **identiques aux réglages des moteurs** |
| `watchdog`, `stream_delay`, `ctrl_hz`, `fb_timeout`, `max_temp` (`*`) | ms, ms, Hz, ms, °C | temporisations et seuils |

## Piloter le robot depuis un script (Python)

ORION Studio n’est pas obligatoire. N’importe quel programme peut parler au firmware, par exemple une IA qui planifie
des gestes dans l’esprit des démonstrations robotiques de GPT-6 Astra :

```python
import time, math, serial   # pip install pyserial

def line(cmd):
    c = 0
    for ch in cmd.encode():
        c ^= ch
    return f"{cmd}*{c:02X}\n".encode()

s = serial.Serial("/dev/ttyACM0", 115200, timeout=0.05)   # Windows : "COM5"
for cmd in ["PING", "EN 1", "HOME"]:
    s.write(line(cmd))
# … attendre « EVT DONE » (lire s.readline()) …

# Flux à 100 Hz : balancement de J1 de ±20° autour de la pose Home
t0, seq = time.monotonic(), 0
while time.monotonic() - t0 < 10:
    t = time.monotonic() - t0
    q = [20 * math.sin(0.5 * t) * min(t, 1.0), 0, 0, 0, 90, 0]
    ms = int((time.monotonic() * 1000)) & 0xFFFF
    s.write(line("SP %d %d %s" % (seq & 0xFFFF, ms, " ".join("%.3f" % v for v in q))))
    seq += 1
    time.sleep(0.01)
```

La rampe `min(t, 1.0)` fait démarrer le flux sur la position actuelle, condition du démarrage. Si le script s’arrête, le
chien de garde immobilise le robot en douceur.

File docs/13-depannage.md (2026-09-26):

# 13. Dépannage

## ORION Studio

| Symptôme | Cause probable | Remède |
|---|---|---|
| Page blanche avec `npm start` | modules non installés | `npm install`, puis `npm start`. Ouvrez bien http://localhost:8080/studio/ |
| Page blanche en ouvrant `studio/index.html` directement | les modules ES ne se chargent pas depuis `file://` | utilisez `npm start`, ou le fichier autonome `dist/ORION-Studio.html` |
| Le modèle 3D reste simplifié (sans pièces CAO) | CAO en cours de génération, ou géométrie DH incompatible avec l’architecture ORION-6 | patientez quelques secondes, ou rechargez le préréglage ORION-6 MAKER |
| *Connecter (USB)* grisé | navigateur sans Web Serial (Firefox, Safari, mobile) | Chrome ou Edge sur ordinateur |
| Le port n’apparaît pas | câble USB de charge seule, pilote, autre logiciel qui occupe le port | câble de données, fermer le moniteur série de l’IDE Arduino |
| « Jumeau numérique » : `ERR 5 flux …` | la simulation est loin de la position réelle | *Synchroniser*, puis relancer le jumeau numérique |
| Mouvements saccadés en jumeau numérique | onglet en arrière-plan (navigateur ralenti), PC chargé | garder l’onglet visible ; augmenter `stream_delay` (60–80 ms) |
| Le robot ne suit plus et `EVT WATCHDOG` apparaît | consignes interrompues (onglet masqué, câble) | normal : arrêt de sécurité. Relancer le jumeau numérique |
| Paramètres « bizarres » après import | valeurs hors plage bornées automatiquement | lire le *Journal* : chaque correction y est listée |
| Revenir aux réglages d’origine | configuration sauvegardée dans le navigateur | *Paramètres* → ⟲ (deux clics) ou choisir un préréglage |

## Simulation et réglage

| Symptôme | Cause probable | Remède |
|---|---|---|
| « Perte de pas » en simulation | couple insuffisant (accélération, charge, vitesse au-delà de la vitesse de coin) | *Analyse → Dimensionnement* ; réduire accélération, jerk ou vitesse ; augmenter la tension ou le courant |
| Oscillations autour de la consigne (PID) | jeu + intégrale, bande passante trop haute | réduire Ki, zone morte ≈ jeu/2, bande passante < f_résonance/3 |
| Le bras « tombe » en compensation de gravité | masses ou centres de masse sous-estimés | corriger *Dynamique*, puis tester de nouveau |
| Arrêt « auto-collision » inattendu | pose réellement en collision, ou capsules trop grosses | vue *Modèle de collision* ; ajuster la *Marge de collision* (*Sécurité*) |
| MoveL très lent par endroits | passage près d’une singularité (re-temporisation) | changer de configuration (solutions IK) ou passer par un MoveJ |
| « cible hors d’atteinte » ou « toutes les solutions sont hors butées » | pose hors de l’espace de travail, orientation impossible ou butées | *Analyse → Espace de travail* ; changer l’orientation ou la configuration demandée |

## Firmware et électronique (ORION-6 MAKER)

| Symptôme | Cause probable | Remède |
|---|---|---|
| Aucune réponse à `PING` | mauvais port, firmware non flashé, câble | LED 13 : un éclair toutes les 2 s = firmware en marche, moteurs coupés ; reflasher le .hex |
| `ERR 7 arret d'urgence actif` | entrée 30 ouverte (champignon enfoncé ou fil coupé) | réarmer ; vérifier le contact NF entre la broche 30 et GND |
| `ERR 4 prise d'origine requise` | robot non référencé (démarrage, `EN 0`, arrêt d’urgence) | `HOME` (ou `ZERO` si le robot est posé en pose Home) |
| `EVT FAULT prise d'origine Jn : capteur introuvable` | capteur débranché, aimant trop loin, mauvais sens de recherche | tester le capteur (drapeau 0x40 de `STAT`) ; `SET home_dir n …` |
| `EVT FAULT fin de course Jn` pendant un mouvement | butée logicielle au-delà du capteur, ou capteur parasité | vérifier `min`/`max` et la position du capteur ; blinder et éloigner le câble du capteur |
| Moteurs qui sifflent sans tourner | câblage de bobine croisé (A+/B+ inversés) | identifier les paires à l’ohmmètre (≈ quelques Ω) |
| Pas manqués aléatoires, même à vide | niveaux 3,3 V insuffisants pour des drivers optocouplés | tampon 74HCT245 en 5 V (voir [9. Électronique](09-electronique.md)) |
| Axe qui tourne à l’envers | câblage moteur | `SET invert n 1` puis `SAVE` |
| Angle réel ≠ angle commandé (échelle) | micro-pas du driver ≠ 16, réduction | vérifier les interrupteurs du driver ; `steps_per_deg` ([12. Calibration](12-calibration.md)) |
| Décalage constant après `HOME` | position du capteur non calibrée | calibrer `home_pos` |
| Drivers chauds, moteurs brûlants | courant trop élevé, pas de réduction au repos | courant ≤ 90 % du nominal ; activer « half current » |
| La Teensy redémarre quand les moteurs démarrent | chute de tension ou masse commune mal faite | alimentation logique séparée (buck 5 V), masse en étoile, condensateur 470 µF sur le 5 V |

## Pont CAN mode MIT (ORION-6 PRO)

| Symptôme | Cause probable | Remède |
|---|---|---|
| `ERR 6 moteur Jn muet` | identifiant faux, moteur non alimenté, bus sans terminaison, CAN_H/CAN_L inversés | mesurer 60 Ω entre CAN_H et CAN_L (hors tension) ; vérifier l’ID avec l’outil du fabricant |
| Positions qui « sautent » ou valeurs aberrantes | plages P/V/T du pont ≠ réglages du moteur | aligner `p_max`/`v_max`/`t_max` sur la configuration du moteur |
| `EVT FAULT CAN : Jn ne repond plus` en fonctionnement | bus saturé (fréquence trop haute), connectique | `SET ctrl_hz * 300`, contrôler les connecteurs, séparer sur deux bus |
| `EVT FAULT Jn : temperature …` | Kp élevé face à une erreur statique permanente (masse fausse), réducteur qui force | corriger la compensation de gravité ; réduire Kp ; laisser refroidir |
| Le bras tombe à l’activation | compensation de gravité absente avant le premier flux | normal sans τff : activer puis lancer rapidement le jumeau numérique ; ou soutenir le bras |
| Vibrations en maintien | Kd trop faible ou trop fort (bruit de vitesse), Kp trop haut | ζ ≈ 0,7–1 ; réduire Kp ; vérifier la rigidité mécanique |
| Pose fausse après remise sous tension | position absolue perdue (réducteur intégré) | poser en pose de repos, `ZERO`, `SAVE` ; toujours vérifier `STAT` avant `EN 1` |

## Mécanique

| Symptôme | Cause probable | Remède |
|---|---|---|
| Réducteur dur ou à points durs | pied d’éléphant sur un disque, galet mal enfoncé, disques A/B inversés | ébavurer, contrôler les galets, vérifier le repère « B » |
| Jeu excessif en sortie | compensation XY trop négative, trous de doigts trop grands | réimprimer les disques après le test de tolérances |
| Craquements sous charge | inserts arrachés, vis trop serrées | reposer les inserts (fer), serrer à la main |
| Le tube glisse dans son raccord | collier desserré | resserrer les vis M4 ; un tour de ruban aluminium en cale |
| Flexion visible du bras | pièces imprimées trop peu remplies | respecter les remplissages indiqués (≥ 45 % pour la structure) |

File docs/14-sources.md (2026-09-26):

# 14. Sources et inspirations

## La démonstration robotique de GPT-6 Astra

La demande à l’origine d’ORION-6 faisait référence au logiciel présenté autour des **robots de GPT-6 Astra**.

- [GPT-6 Astra: A new generation of intelligence](https://openai.com/index/gpt-6-astra/) (OpenAI).
- [GPT-6 Astra: The next generation in intelligence for work](https://openai.com/index/gpt-6-astra-next-generation-work/)
  (OpenAI).

Selon les sources consultées, GPT-6 Astra pilotait une paire de **bras YAM**. Il y apportait le jugement et la
correction au niveau « sémantique », tandis qu’une politique motrice gérait l’interaction physique. Il a par exemple
réussi 19 fois sur 20 à déposer un bloc dans un bol.

- [awesome-gpt-6-astra](https://github.com/magiccreator-ai/awesome-gpt-6-astra) : liste des démonstrations publiées
  (jeux, Blender et 3D, mécanismes).

Idées reprises dans ORION-6 :

- un logiciel unique qui sert à la fois de **jumeau numérique**, d’outil de réglage et de programmation, et
  d’**interface en langage naturel** ;
- des bras à **moteurs brushless sur bus CAN, commandés en mode MIT avec compensation de gravité** : variante PRO ;
- un **protocole ouvert et scriptable** : ORION-ASCII, utilisable depuis n’importe quel programme, IA comprise (voir
  l’exemple Python de [11. Firmware](11-firmware-protocole.md)).

## Bras YAM (i2rt)

- [i2rt-robotics/i2rt](https://github.com/i2rt-robotics/i2rt) : bibliothèque Python des bras YAM. Elle documente :
  - des moteurs Damiao (DM3507, DM4310, DM4340) sur CAN à 1 Mbit/s ;
  - le mode MIT et la compensation de gravité (*zero-gravity mode*) ;
  - l’intégration MuJoCo et les modèles URDF/MJCF ;
  - un **délai de sécurité de 400 ms** au-delà duquel les moteurs passent en amortissement.
- Les bras YAM ont 6 axes. Leurs versions vont de 2 à 4 kg de charge, pour environ 780 mm de portée.

Ce qu’ORION-6 en reprend :

- la loi PD + compensation de gravité ;
- l’export MJCF (MuJoCo) ;
- le chien de garde du pont MIT. Celui-ci **maintient** la dernière consigne avec son couple de gravité plutôt que
  d’amortir, pour ne pas laisser retomber le bras. L’amortissement est réservé aux défauts moteur.

Actionneurs de référence de la variante PRO :

- [Damiao DM-J4340-2EC](https://aifitlab.com/products/damiao-dm-j4340-2ec-servo-motor) (fiche revendeur) ;
- Damiao DM-J4310 pour le poignet.

## Defend Intelligence (YouTube)

- [Chaîne Defend Intelligence](https://www.youtube.com/@DefendIntelligence) : vulgarisation de l’IA en français.
- [« Création bras Robot qui apprend »](https://www.youtube.com/shorts/8peRzwpX3AY) (#robot #ai #lerobot #blender) :
  construction d’un bras qui apprend par démonstration, avec l’écosystème LeRobot.

Je n’ai pas retrouvé de description publique détaillée d’un logiciel qu’il aurait créé pour la présentation de
GPT-6 Astra. ORION Studio reprend donc l’esprit général de ces démonstrations : bras imprimé, simulation 3D, pilotage
par l’IA et apprentissage. Il n’est pas une copie d’un logiciel existant.

## Bras open source imprimés (YouTube et GitHub)

- **SO-100 / SO-101** et **LeRobot** (Hugging Face) :
  [github.com/TheRobotStudio/SO-ARM100](https://github.com/TheRobotStudio/SO-ARM100),
  [github.com/huggingface/lerobot](https://github.com/huggingface/lerobot). Bras bon marché à servos, référence pour
  l’apprentissage par imitation.
- **AR4** (Annin Robotics), [anninrobotics.com](https://www.anninrobotics.com) : bras 6 axes à pas-à-pas et Teensy.
  Il a inspiré le choix Teensy + drivers pas-à-pas + capteurs d’origine d’ORION-6 MAKER.
- **BCN3D Moveo**, [github.com/BCN3D/BCN3D-Moveo](https://github.com/BCN3D/BCN3D-Moveo) : bras imprimé historique
  (pas-à-pas, courroies).
- **Thor**, [github.com/AngelLM/Thor](https://github.com/AngelLM/Thor) : bras 6 axes imprimé open source.
- **Dummy Robot** (Peng Zhihui), [github.com/peng-zhihui/Dummy-Robot](https://github.com/peng-zhihui/Dummy-Robot) :
  petit bras 6 axes à servos pas-à-pas en boucle fermée, très compact.

## Références techniques

- **Mode MIT** :
  - B. Katz, *A Low Cost Modular Actuator for Dynamic Robots*, mémoire de master, MIT, 2018 ;
  - B. Katz, J. Di Carlo, S. Kim, *Mini Cheetah: A Platform for Pushing the Limits of Dynamic Quadruped Control*,
    ICRA 2019.

  Ces travaux sont à l’origine du format de trame p/v/Kp/Kd/τ repris par les moteurs QDD.
- **Robotique générale** : B. Siciliano, L. Sciavicco, L. Villani, G. Oriolo, *Robotics: Modelling, Planning and
  Control*, Springer, 2009 (DH, modèle inverse, jacobien, commande).
- **Dynamique** : R. Featherstone, *Rigid Body Dynamics Algorithms*, Springer, 2008 (RNEA, CRBA).
- **Articulation flexible** : M. W. Spong, *Modeling and Control of Elastic Joint Robots*, ASME J. Dyn. Sys. Meas.
  Control, 1987.
- **Trajectoires** : L. Biagiotti, C. Melchiorri, *Trajectory Planning for Automatic Machines and Robots*, Springer,
  2008 (courbe en S à 7 phases).
- **Frottement** : H. Olsson, K. J. Åström et al., *Friction Models and Friction Compensation*, European Journal of
  Control, 1998 (effet Stribeck).
- **Manipulabilité** : T. Yoshikawa, *Manipulability of Robotic Mechanisms*, IJRR, 1985.

## Logiciels et bibliothèques utilisés

- [three.js](https://threejs.org) (licence MIT) : rendu 3D d’ORION Studio.
- [manifold-3d](https://github.com/elalish/manifold) (licence Apache-2.0) : géométrie de construction solide robuste,
  pour la CAO paramétrique et l’export STL.
- [esbuild](https://esbuild.github.io) : regroupement du fichier autonome.
- Cœur Teensy ([PaulStoffregen/cores](https://github.com/PaulStoffregen/cores)), EEPROM et
  [FlexCAN_T4](https://github.com/tonton81/FlexCAN_T4) : compilation des firmwares.

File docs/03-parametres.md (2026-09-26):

<!-- FICHIER GÉNÉRÉ par tools/gen-docs.mjs depuis studio/core/schema.js et studio/core/defaults.js — ne pas modifier à la main. -->

# 3. Référence de tous les paramètres

ORION Studio expose **179 paramètres** (soit **567 valeurs** en comptant chaque articulation). Ils sont tous modifiables en direct dans l’onglet **Paramètres** (champ de recherche, aide au survol de `?`), enregistrés dans le fichier de configuration `JSON` et, pour ceux qui concernent le matériel, exportés vers le firmware (`orion_config.h` ou commandes `SET`).

- Les valeurs sont stockées en unités SI (m, rad, kg, s) et **affichées** dans les unités du tableau (mm, °, g·cm²…).
- La colonne *Valeur* donne le réglage du préréglage **ORION-6 MAKER** (pas-à-pas + réducteurs cycloïdaux imprimés) ; lorsque le préréglage **ORION-6 PRO** (moteurs QDD en mode MIT) diffère, sa valeur est indiquée en italique.
- Pour les tableaux par articulation, les valeurs sont données dans l’ordre J1 · J2 · J3 · J4 · J5 · J6.
- La validation borne automatiquement toute valeur hors plage (import JSON compris) et signale la correction dans le journal.

## Sommaire

- [Général](#général)
- [Cinématique (Denavit-Hartenberg)](#cinématique-denavit-hartenberg)
- [Limites & performances](#limites--performances)
- [Dynamique (masses & inerties)](#dynamique-masses--inerties)
- [Actionneurs (moteurs & réducteurs)](#actionneurs-moteurs--réducteurs)
- [Commande (PID, mode MIT, couple calculé)](#commande-pid-mode-mit-couple-calculé)
- [Trajectoires & modèle inverse](#trajectoires--modèle-inverse)
- [Pince / outil](#pince--outil)
- [Sécurité](#sécurité)
- [Simulation](#simulation)
- [Matériel & firmware](#matériel--firmware)
- [Poses nommées](#poses-nommées)

## Général

Identité du robot et variante matérielle.

| Paramètre | Clé | Unité | Plage | Valeur ORION-6 MAKER | Rôle |
|---|---|---|---|---|---|
| Nom du robot | `meta.name` |  |  | « ORION-6 » | Nom affiché dans l’interface et utilisé pour les exports (URDF, MJCF, firmware). *PRO : « ORION-6 PRO »* |
| Variante matérielle | `meta.variant` |  | `maker`, `pro`, `custom` | MAKER — NEMA17/23 + réducteurs cycloïdaux imprimés | Change uniquement l’étiquette et les valeurs proposées par les préréglages. Tous les paramètres restent modifiables individuellement. *PRO : PRO — actionneurs brushless QDD en mode MIT (CAN)* |
| Description | `meta.description` |  |  | « Bras 6 axes imprimé en 3D — NEMA17/23 + réducteurs cycloïdaux imprimés, Teensy 4.1. » | Notes libres enregistrées avec la configuration. *PRO : « Variante à actionneurs brushless QDD pilotés en mode MIT sur bus CAN (type Damiao DM4340 / DM4310), PD + compensation de gravité. »* |

## Cinématique (Denavit-Hartenberg)

Géométrie du bras : table DH, repère de base et outil (TCP). Ces paramètres définissent le modèle géométrique direct et inverse.

| Paramètre | Clé | Unité | Plage | Valeur ORION-6 MAKER | Rôle |
|---|---|---|---|---|---|
| Convention DH | `kinematics.convention` |  | `DH`, `MDH` | DH standard (Denavit-Hartenberg classique) | Standard : Aᵢ = Rz(θᵢ)·Tz(dᵢ)·Tx(aᵢ)·Rx(αᵢ), l’axe de l’articulation i est zᵢ₋₁. Modifiée (Craig) : Aᵢ = Rx(αᵢ₋₁)·Tx(aᵢ₋₁)·Rz(θᵢ)·Tz(dᵢ), l’axe i est zᵢ. Le modèle inverse analytique n’est disponible qu’en DH standard ; en DH modifiée le solveur numérique est utilisé. |
| **Table DH** — tableau par articulation (J1 · J2 · … · J6) | `kinematics.joints[i]` | | | | Une ligne par articulation (J1 = base … J6 = poignet). Unités d’affichage : mm et degrés. |
| ↳ Nom | `.name` |  |  | « J1 Base » · « J2 Épaule » · « J3 Coude » · « J4 Avant-bras » · « J5 Poignet » · « J6 Bride » | Nom de l’axe (affiché dans l’interface). |
| ↳ Type | `.type` |  | `revolute`, `prismatic` | Rotoïde (tous) | Rotoïde : θ varie. Prismatique : d varie (glissière). |
| ↳ a — longueur | `.a` | mm | -2000 … 2000 | 0 · 240 · 0 · 0 · 0 · 0 | Distance entre les axes zᵢ₋₁ et zᵢ mesurée le long de xᵢ (DH standard). |
| ↳ α — torsion | `.alpha` | ° | -180 … 180 | -90 · 0 · -90 · 90 · -90 · 0 | Angle entre zᵢ₋₁ et zᵢ autour de xᵢ. |
| ↳ d — décalage | `.d` | mm | -2000 … 2000 | 160 · 0 · 0 · 220 · 0 · 33,2 | Distance entre xᵢ₋₁ et xᵢ le long de zᵢ₋₁. |
| ↳ θ₀ — décalage zéro | `.thetaOffset` | ° | -180 … 180 | 0 · -90 · 0 · 0 · 0 · 0 | Décalage entre la valeur articulaire q et l’angle DH : θ = sens·q + θ₀. Permet de choisir la pose « zéro » mécanique. |
| ↳ Sens (+1/−1) | `.direction` |  | -1 … 1 | 1 (tous) | Inverse le sens positif de l’axe sans changer la géométrie (θ = sens·q + θ₀). |
| Base — X | `kinematics.base.x` | mm | -5000 … 5000 | 0 | Position du repère de base du robot dans le monde (ex. table). |
| Base — Y | `kinematics.base.y` | mm | -5000 … 5000 | 0 |  |
| Base — Z | `kinematics.base.z` | mm | -5000 … 5000 | 0 | Hauteur de la base au-dessus du plan de travail. |
| Base — roulis (Rx) | `kinematics.base.roll` | ° | -180 … 180 | 0 | Orientation de la base (montage mural/plafond : ±90° / 180°). |
| Base — tangage (Ry) | `kinematics.base.pitch` | ° | -180 … 180 | 0 |  |
| Base — lacet (Rz) | `kinematics.base.yaw` | ° | -180 … 180 | 0 |  |
| Outil — nom | `kinematics.tool.name` |  |  | « Pince parallèle » | Nom de l’outil monté sur la bride (pince, ventouse, stylo…). |
| TCP — X | `kinematics.tool.x` | mm | -1000 … 1000 | 0 | Position du point outil (TCP) dans le repère de la bride (repère 6). |
| TCP — Y | `kinematics.tool.y` | mm | -1000 … 1000 | 0 |  |
| TCP — Z | `kinematics.tool.z` | mm | -1000 … 1000 | 100,3 | Longueur de l’outil le long de l’axe de la bride. |
| TCP — Rx | `kinematics.tool.roll` | ° | -180 … 180 | 0 |  |
| TCP — Ry | `kinematics.tool.pitch` | ° | -180 … 180 | 0 |  |
| TCP — Rz | `kinematics.tool.yaw` | ° | -180 … 180 | 0 |  |

## Limites & performances

Butées logicielles, vitesses, accélérations et jerks maximaux (articulaires et cartésiens).

| Paramètre | Clé | Unité | Plage | Valeur ORION-6 MAKER | Rôle |
|---|---|---|---|---|---|
| **Limites articulaires** — tableau par articulation (J1 · J2 · … · J6) | `limits.joints[i]` | | | |  |
| ↳ Butée min | `.min` | ° | -360 … 360 | -170 · -130 · -170 · -170 · -115 · -180 | Butée logicielle basse. Doit rester à l’intérieur de la butée mécanique. |
| ↳ Butée max | `.max` | ° | -360 … 360 | 170 · 130 · 60 · 170 · 115 · 180 | Butée logicielle haute. |
| ↳ Vitesse max | `.vmax` | °/s | 0,6 … 2864,8 | 120 · 90 · 110 · 170 · 170 · 200 | Vitesse articulaire maximale utilisée par le planificateur (100 % de vitesse). *PRO : 150 · 120 · 150 · 360 · 360 · 360* |
| ↳ Accélération max | `.amax` | °/s² | 1 … 28 648 | 300 · 200 · 300 · 600 · 600 · 700 | Accélération articulaire maximale. *PRO : 400 · 300 · 400 · 900 · 900 · 900* |
| ↳ Jerk max | `.jmax` | °/s³ | 6 … 2 864 789 | 3000 · 2000 · 3000 · 6000 · 6000 · 7000 | Dérivée de l’accélération (profil en S). Plus faible = mouvements plus doux, moins de vibrations. *PRO : 4000 · 3000 · 4000 · 9000 · 9000 · 9000* |
| Vitesse TCP max | `limits.cartesian.vmax` | mm/s | 1 … 5000 | 250 | Vitesse linéaire maximale du point outil pour les mouvements linéaires/circulaires (MoveL/MoveC). |
| Accélération TCP max | `limits.cartesian.amax` | mm/s² | 10 … 50 000 | 1000 |  |
| Jerk TCP max | `limits.cartesian.jmax` | mm/s³ | 100 … 1 000 000 | 10 000 |  |
| Vitesse angulaire outil max | `limits.cartesian.wmax` | °/s | 0,6 … 1145,9 | 90 |  |
| Accélération angulaire outil max | `limits.cartesian.alphamax` | °/s² | 1 … 11 459 | 360 |  |
| Boîte de sécurité active | `limits.workspace.enabled` |  | oui / non | non | Refuse tout mouvement dont le TCP sortirait de la boîte définie ci-dessous (repère monde). |
| Boîte — X min | `limits.workspace.xmin` | mm | -5000 … 5000 | -700 |  |
| Boîte — X max | `limits.workspace.xmax` | mm | -5000 … 5000 | 700 |  |
| Boîte — Y min | `limits.workspace.ymin` | mm | -5000 … 5000 | -700 |  |
| Boîte — Y max | `limits.workspace.ymax` | mm | -5000 … 5000 | 700 |  |
| Boîte — Z min | `limits.workspace.zmin` | mm | -5000 … 5000 | 5 | Mettre légèrement au-dessus de la table pour protéger l’outil. |
| Boîte — Z max | `limits.workspace.zmax` | mm | -5000 … 5000 | 900 |  |
| Hauteur du plan de travail | `limits.floorZ` | mm | -2000 … 2000 | 0 | Altitude de la table dans le repère monde, utilisée pour la détection de collision avec le sol. |

## Dynamique (masses & inerties)

Paramètres inertiels des segments, de l’outil et de la charge, frottements. Utilisés par la simulation, la compensation de gravité, le couple calculé et le dimensionnement. Valeurs par défaut calculées depuis la CAO (PLA, remplissage indiqué) + moteurs + visserie.

| Paramètre | Clé | Unité | Plage | Valeur ORION-6 MAKER | Rôle |
|---|---|---|---|---|---|
| Gravité | `dynamics.gravity` | m/s² |  | 0 / 0 / -9,81 | Vecteur gravité dans le repère monde (par défaut [0, 0, −9,81]). |
| **Segments** — tableau par articulation (J1 · J2 · … · J6) | `dynamics.links[i]` | | | |  |
| ↳ Masse | `.mass` | kg | 0 … 50 | 1,808 · 1,211 · 0,744 · 0,708 · 0,52 · 0,049 | Masse du segment i (pièces imprimées + moteur/stator porté + visserie). *PRO : 0,711 · 0,755 · 0,585 · 0,551 · 0,413 · 0,12* |
| ↳ CdG x | `.com.0` | mm | -1000 … 1000 | 0 · -58,21 · 0 · 0 · 0 · 0 | Centre de gravité exprimé dans le repère DH i du segment. *PRO : 0 · -98,95 · 0 · 0 · 0 · 0* |
| ↳ CdG y | `.com.1` | mm | -1000 … 1000 | 4,13 · -0 · -5,74 · -31,16 · -8,57 · 0 |  *PRO : 26,85 · -0 · -26,51 · -69,65 · -34,37 · 0* |
| ↳ CdG z | `.com.2` | mm | -1000 … 1000 | -11,32 · 83,66 · 22,7 · 72,99 · -3,93 · -9,88 |  *PRO : -18,62 · 67,25 · 12,71 · 58,19 · -8,79 · -49,15* |
| ↳ Ixx | `.inertia.0` | kg·cm² | 0 … 100 000 | 33,857 · 14,652 · 9,024 · 34,486 · 5,539 · 0,103 | Tenseur d’inertie au centre de gravité, axes du repère i. *PRO : 27,932 · 23,291 · 19,721 · 53,896 · 14,282 · 1,35* |
| ↳ Iyy | `.inertia.1` | kg·cm² | 0 … 100 000 | 29,588 · 117,43 · 7,223 · 15,127 · 3,379 · 0,103 |  *PRO : 11,8 · 103,32 · 7,371 · 18,384 · 4,729 · 1,35* |
| ↳ Izz | `.inertia.2` | kg·cm² | 0 … 100 000 | 22,779 · 110,71 · 7,534 · 23,151 · 5,045 · 0,167 |  *PRO : 27,297 · 87,965 · 19,733 · 40,81 · 14,09 · 1,35* |
| ↳ Ixy | `.inertia.3` | kg·cm² | -100 000 … 100 000 | -0 · -0 · -0 · 0 · -0 · 0 |  *PRO : 0 · -0 · -0 · 0 · -0 · 0* |
| ↳ Ixz | `.inertia.4` | kg·cm² | -100 000 … 100 000 | 0,005 · -18,409 · -0,001 · -0 · -0,001 · 0 |  *PRO : 0 · -29,71 · -0 · 0 · 0 · 0* |
| ↳ Iyz | `.inertia.5` | kg·cm² | -100 000 … 100 000 | -0,642 · -0,002 · -1,078 · -13,764 · 0,205 · -0 |  *PRO : -3,352 · 0 · -2,077 · -20,01 · 1,278 · 0* |
| Outil — masse | `dynamics.tool.mass` | kg | 0 … 20 | 0,156 | Masse de l’outil (pince + servo + bride). |
| Outil — CdG (repère bride) | `dynamics.tool.com` | mm |  | -1,96 / -0,01 / 35,26 |  |
| Outil — inertie (Ixx, Iyy, Izz) | `dynamics.tool.inertiaDiag` | kg·cm² |  | 1,258 / 1,756 / 0,834 |  |
| Charge — masse | `dynamics.payload.mass` | kg | 0 … 20 | 0,2 | Masse de l’objet manipulé. Utilisée quand la pince est fermée sur un objet (et pour le dimensionnement). |
| Charge — CdG (repère TCP) | `dynamics.payload.com` | mm |  | 0 / 0 / 0 |  |
| Charge nominale (dimensionnement) | `dynamics.payloadRated` | kg | 0 … 20 | 0,5 | Charge utile maximale annoncée, utilisée par l’analyse de dimensionnement. |
| **Frottements (côté articulation)** — tableau par articulation (J1 · J2 · … · J6) | `dynamics.friction[i]` | | | |  |
| ↳ Coulomb | `.coulomb` | N·m | 0 … 50 | 0,35 · 0,7 · 0,45 · 0,15 · 0,15 · 0,1 | Couple de frottement sec (réducteur + roulements), ramené à la sortie. *PRO : 0,25 · 0,25 · 0,25 · 0,08 · 0,08 · 0,08* |
| ↳ Visqueux | `.viscous` | N·m·s/rad | 0 … 50 | 0,3 · 0,6 · 0,4 · 0,1 · 0,1 · 0,08 | Coefficient de frottement visqueux (couple ∝ vitesse). *PRO : 0,08 · 0,08 · 0,08 · 0,03 · 0,03 · 0,03* |
| ↳ Adhérence | `.stiction` | N·m | 0 … 50 | 0,45 · 0,9 · 0,6 · 0,2 · 0,2 · 0,14 | Couple de décollement (≥ Coulomb). Modèle de Stribeck. *PRO : 0,3 · 0,3 · 0,3 · 0,1 · 0,1 · 0,1* |
| ↳ Vitesse de Stribeck | `.stribeckVel` | °/s | 0 … 57,3 | 1,1 (tous) | Vitesse caractéristique de la transition adhérence → glissement. |

## Actionneurs (moteurs & réducteurs)

Modèle de chaque actionneur : type, réduction, rendement, caractéristiques électriques et mécaniques. Les couples/vitesses « de sortie » s’entendent côté articulation.

| Paramètre | Clé | Unité | Plage | Valeur ORION-6 MAKER | Rôle |
|---|---|---|---|---|---|
| Tension d’alimentation | `actuators.supplyVoltage` | V | 5 … 80 | 36 | Tension du bus moteurs. Détermine la chute de couple des pas-à-pas à haute vitesse. *PRO : 24* |
| **Actionneurs** — tableau par articulation (J1 · J2 · … · J6) | `actuators.joints[i]` | | | |  |
| ↳ Type | `.type` |  | `stepper`, `bldc_mit`, `servo` | Pas-à-pas + réducteur (boucle ouverte) (tous) | Modèle physique utilisé par la simulation. *PRO : Brushless QDD « mode MIT » (CAN) (tous)* |
| ↳ Référence | `.model` |  |  | « NEMA17-48 + cycloïdal CY-M 25:1 » · « NEMA23-76 + cycloïdal CY-L 30:1 » · « NEMA17-60 + cycloïdal CY-M 25:1 » · « NEMA17-40 + cycloïdal CY-S 20:1 » · « NEMA17-40 + cycloïdal CY-S 20:1 » · « NEMA17-34 + cycloïdal CY-S 20:1 » | Référence du moteur / module (documentation, nomenclature). *PRO : « DM4340 (QDD, mode MIT) » · « DM4340 (QDD, mode MIT) » · « DM4340 (QDD, mode MIT) » · « DM4310 (QDD, mode MIT) » · « DM4310 (QDD, mode MIT) » · « DM4310 (QDD, mode MIT) »* |
| ↳ Réduction | `.gearRatio` | :1 | 1 … 500 | 25 · 30 · 25 · 20 · 20 · 20 | Rapport de réduction N (moteur/sortie). Réducteur cycloïdal : N = nombre de lobes = nb de galets − 1. *PRO : 40 · 40 · 40 · 10 · 10 · 10* |
| ↳ Rendement | `.efficiency` | % | 10 … 100 | 70 (tous) | Rendement du réducteur (couple sortie = N·η·couple moteur). *PRO : 90 (tous)* |
| ↳ Inertie rotor | `.rotorInertia` | g·cm² | 0 … 100 000 | 82 · 480 · 102 · 54 · 54 · 34 | Inertie du rotor moteur. Ramenée à la sortie : N²·J_rotor (souvent dominante !). *PRO : 150 · 150 · 150 · 60 · 60 · 60* |
| ↳ Jeu (backlash) | `.backlash` | ° | 0 … 5,73 | 0,25 · 0,2 · 0,25 · 0,35 · 0,35 · 0,4 | Jeu angulaire total en sortie de réducteur. *PRO : 0,15 (tous)* |
| ↳ Raideur transmission | `.stiffness` | N·m/rad | 10 … 1 000 000 | 2500 · 4000 · 2500 · 800 · 800 · 600 | Raideur torsionnelle du réducteur (sortie). Utilisée avec le jeu. *PRO : 6000 · 6000 · 6000 · 2000 · 2000 · 2000* |
| ↳ Couple de maintien | `.holdingTorque` | N·m | 0 … 20 | 0,59 · 1,89 · 0,65 · 0,42 · 0,42 · 0,28 | [Pas-à-pas] Couple de maintien du moteur (fiche technique) au courant nominal. *PRO : 0 (tous)* |
| ↳ Angle de pas | `.stepAngle` | ° | 0,06 … 11,46 | 1,8 (tous) | [Pas-à-pas] 1,8° (200 pas/tour) ou 0,9° (400 pas/tour). |
| ↳ Micro-pas | `.microsteps` |  | 1 … 256 | 16 (tous) | [Pas-à-pas] Subdivision réglée sur le driver (DIP/UART). *PRO : 1 (tous)* |
| ↳ Courant nominal | `.ratedCurrent` | A | 0 … 20 | 2 · 2,8 · 2,1 · 1,7 · 1,7 · 1,3 | [Pas-à-pas] Courant par phase de la fiche technique. *PRO : 0 (tous)* |
| ↳ Courant de travail | `.runCurrent` | A | 0 … 20 | 1,8 · 2,52 · 1,89 · 1,53 · 1,53 · 1,17 | [Pas-à-pas] Courant réglé sur le driver. Couple ≈ proportionnel. *PRO : 0 (tous)* |
| ↳ Résistance de phase | `.phaseResistance` | Ω | 0,01 … 100 | 1,4 · 1,13 · 1,6 · 1,5 · 1,5 · 2,4 |  *PRO : 1 (tous)* |
| ↳ Inductance de phase | `.phaseInductance` | mH | 0,01 … 100 | 3 · 3,6 · 3 · 2,8 · 2,8 · 2,8 | [Pas-à-pas] Limite la montée du courant à haute vitesse → chute de couple. *PRO : 1 (tous)* |
| ↳ Couple crête (sortie) | `.peakTorque` | N·m | 0 … 500 | 10,32 · 39,69 · 11,38 · 5,88 · 5,88 · 3,92 | [Brushless/servo] Couple maximal en sortie de réducteur. *PRO : 27 · 27 · 27 · 7 · 7 · 7* |
| ↳ Couple nominal (sortie) | `.ratedTorque` | N·m | 0 … 500 | 6,19 · 23,81 · 6,83 · 3,53 · 3,53 · 2,35 | [Brushless/servo] Couple continu admissible (échauffement). *PRO : 9 · 9 · 9 · 3 · 3 · 3* |
| ↳ Vitesse à vide (sortie) | `.maxSpeed` | tr/min | 1 … 9549,3 | 24 · 20 · 24 · 30 · 30 · 30 | [Brushless/servo] Vitesse à vide en sortie. Le couple disponible décroît linéairement jusqu’à cette vitesse. *PRO : 52 · 52 · 52 · 200 · 200 · 200* |
| ↳ Constante de couple (sortie) | `.torqueConstant` | N·m/A | 0 … 100 | 0 (tous) | [Brushless/servo] Kt ramené à la sortie (N·m/A). *PRO : 4,4 · 4,4 · 4,4 · 0,945 · 0,945 · 0,945* |
| ↳ Résolution codeur | `.encoderCpr` |  | 0 … 16 777 216 | 4096 (tous) | Points par tour (côté indiqué ci-dessous). 0 = pas de codeur. *PRO : 16 384 (tous)* |
| ↳ Codeur en sortie | `.encoderOnOutput` |  | oui / non | oui (tous) | Coché : codeur absolu sur l’arbre de sortie (ex. AS5600/MT6701). Sinon : codeur moteur. |
| ↳ ID CAN | `.canId` |  | 0 … 2047 | 1 · 2 · 3 · 4 · 5 · 6 | [Mode MIT] Identifiant CAN du moteur (esclave). |
| ↳ P_MAX | `.pMax` | ° | 5,73 … 5729,58 | 716,2 (tous) | [Mode MIT] Plage de position du protocole (±P_MAX rad) — doit correspondre à la configuration du moteur. |
| ↳ V_MAX | `.vMax` | °/s | 5,7 … 28 647,9 | 458,4 (tous) | [Mode MIT] Plage de vitesse du protocole (±V_MAX rad/s). *PRO : 458,4 · 458,4 · 458,4 · 1718,9 · 1718,9 · 1718,9* |
| ↳ T_MAX | `.tMax` | N·m | 0,1 … 500 | 28 (tous) | [Mode MIT] Plage de couple du protocole (±T_MAX N·m). *PRO : 28 · 28 · 28 · 10 · 10 · 10* |
| ↳ KP_MAX | `.kpMax` | N·m/rad | 1 … 5000 | 500 (tous) | [Mode MIT] Borne haute du gain Kp codé sur 12 bits (souvent 500). |
| ↳ KD_MAX | `.kdMax` | N·m·s/rad | 0,1 … 100 | 5 (tous) | [Mode MIT] Borne haute du gain Kd codé sur 12 bits (souvent 5). |

## Commande (PID, mode MIT, couple calculé)

Stratégie de commande et gains. Le mode « pas-à-pas » reproduit le comportement réel des moteurs pas-à-pas en boucle ouverte (y compris la perte de pas). Les autres modes supposent des actionneurs pilotés en couple.

| Paramètre | Clé | Unité | Plage | Valeur ORION-6 MAKER | Rôle |
|---|---|---|---|---|---|
| Mode de commande | `control.mode` |  | `stepper`, `pid`, `mit`, `computed_torque`, `impedance`, `gravity_comp` | Pas-à-pas boucle ouverte (consigne de position) | PID : τ = Kp·e + Ki·∫e + Kd·ė + anticipations. MIT : τ = Kp·(p*−p) + Kd·(v*−v) + τff (exécuté dans le driver du moteur). Couple calculé : τ = M(q)·(q̈* + Kp·e + Kd·ė) + C(q,q̇)·q̇ + g(q). Impédance : τ = Jᵀ·(Kx·Δx + Dx·Δẋ) + g(q). Gravité : τ = g(q) — le bras flotte et se déplace à la main. *PRO : Mode MIT : Kp·(p*−p) + Kd·(v*−v) + τff* |
| Fréquence de boucle | `control.loopHz` | Hz | 50 … 20 000 | 1000 | Fréquence d’échantillonnage du correcteur (bloqueur d’ordre 0 entre deux échantillons). Une fréquence trop basse rend les gains élevés instables — comme sur le vrai robot. |
| Anticipation gravité | `control.feedforward.gravity` |  | oui / non | oui | Ajoute g(q) calculé par le modèle dynamique (indispensable pour des gains faibles / compliance). |
| Anticipation frottements | `control.feedforward.friction` |  | oui / non | oui | Ajoute une estimation des frottements (Coulomb + visqueux) dans le sens de la vitesse désirée. |
| Anticipation inertie | `control.feedforward.inertia` |  | oui / non | oui | Ajoute M(q)·q̈* : améliore fortement le suivi de trajectoire. |
| Erreur de modèle (test) | `control.modelError` | % | 0 … 50 | 0 | Perturbe volontairement les masses du modèle utilisé par le correcteur pour tester la robustesse (0 % = modèle parfait). |
| **Gains articulaires** — tableau par articulation (J1 · J2 · … · J6) | `control.joints[i]` | | | |  |
| ↳ PID — Kp | `.kp` | N·m/rad | 0 … 100 000 | 700 · 1100 · 500 · 80 · 80 · 40 | Gain proportionnel (couple par radian d’erreur). |
| ↳ PID — Ki | `.ki` | N·m/(rad·s) | 0 … 1 000 000 | 3500 · 5500 · 2500 · 400 · 400 · 200 | Gain intégral : annule l’erreur statique. Trop élevé → dépassement/oscillations. |
| ↳ PID — Kd | `.kd` | N·m·s/rad | 0 … 10 000 | 22 · 35 · 15 · 2,5 · 2,5 · 1,2 | Gain dérivé (amortissement). Calculé sur la mesure (pas de coup de dérivée sur échelon). |
| ↳ PID — limite intégrale | `.iLimit` | N·m | 0 … 500 | 5 · 8 · 5 · 2 · 2 · 1 | Saturation du terme intégral (anti-emballement / anti-windup). |
| ↳ PID — filtre dérivée | `.dFilterHz` | Hz | 1 … 5000 | 150 · 150 · 150 · 200 · 200 · 200 | Fréquence de coupure du filtre passe-bas du terme dérivé (réduit le bruit de mesure). |
| ↳ Zone morte | `.deadband` | ° | 0 … 2,86 | 0 (tous) | Erreur en dessous de laquelle le correcteur n’agit pas (évite le « pompage » dû au jeu). |
| ↳ MIT — Kp | `.mitKp` | N·m/rad | 0 … 5000 | 90 · 130 · 90 · 30 · 30 · 15 | Raideur du mode MIT (dans le driver moteur). Typique 20–150 N·m/rad pour un bras de bureau. *PRO : 80 · 120 · 80 · 30 · 25 · 15* |
| ↳ MIT — Kd | `.mitKd` | N·m·s/rad | 0 … 100 | 3 · 4 · 2,5 · 1 · 1 · 0,5 | Amortissement du mode MIT. Typique 0,5–5 N·m·s/rad. *PRO : 2,5 · 3,5 · 2,5 · 1 · 0,8 · 0,5* |
| ↳ Limite de couple | `.torqueLimit` | % | 5 … 100 | 100 (tous) | Fraction du couple disponible autorisée (protection mécanique). |
| Impédance — raideur linéaire | `control.impedance.kTrans` | N/mm | 0 … 100 | 0,8 | Raideur cartésienne du TCP en translation. |
| Impédance — raideur angulaire | `control.impedance.kRot` | N·m/rad | 0 … 1000 | 15 | Raideur cartésienne en rotation. |
| Impédance — amortissement ζ | `control.impedance.zeta` |  | 0 … 3 | 1 | Taux d’amortissement critique visé (1 = critique). |
| Impédance — amortissement articulaire | `control.impedance.nullKd` | N·m·s/rad | 0 … 100 | 0,5 | Amortissement articulaire additionnel (espace nul, stabilité). |
| Auto-réglage — bande passante | `control.autotune.bandwidthHz` | Hz | 0,5 … 100 | 8 | Bande passante visée par le placement de pôles : Kp = J·ω², Kd = 2·ζ·J·ω, Ki = Kp·ω/10 avec J = inertie vue par l’axe. |
| Auto-réglage — amortissement ζ | `control.autotune.zeta` |  | 0,3 … 2 | 0,9 | 0,7 : réponse rapide avec léger dépassement ; 1 : critique, sans dépassement. |

## Trajectoires & modèle inverse

Génération de mouvements (profils de vitesse, lissage) et solveur de cinématique inverse.

| Paramètre | Clé | Unité | Plage | Valeur ORION-6 MAKER | Rôle |
|---|---|---|---|---|---|
| Profil de vitesse | `trajectory.profile` |  | `scurve`, `trapezoid`, `quintic`, `cycloidal` | Courbe en S (jerk limité, 7 phases) | Courbe en S : accélération continue (recommandé pour limiter les vibrations des réducteurs imprimés). |
| Vitesse globale | `trajectory.speedOverride` | % | 1 … 100 | 50 | Facteur appliqué à toutes les vitesses programmées (override). |
| Facteur d’accélération | `trajectory.accelScale` | % | 1 … 100 | 100 | Facteur appliqué aux accélérations et jerks maximaux. |
| Zone de lissage par défaut | `trajectory.blendRadius` | mm | 0 … 200 | 5 | Rayon de passage (« fly-by ») entre deux mouvements consécutifs. 0 = arrêt précis sur chaque point. |
| Échantillonnage cartésien | `trajectory.sampleHz` | Hz | 20 … 2000 | 250 | Fréquence de discrétisation des trajectoires linéaires/circulaires (IK à chaque échantillon). |
| Solveur IK | `trajectory.ik.method` |  | `auto`, `analytic`, `numeric` | Automatique (analytique si possible, sinon numérique) | L’analytique donne jusqu’à 8 solutions exactes ; le numérique fonctionne pour toute géométrie. |
| Configuration préférée | `trajectory.ik.configuration` |  | `closest`, `front-up-noflip`, `front-down-noflip`, `front-up-flip`, `back-up-noflip` | La plus proche de la position actuelle | Choix parmi les solutions analytiques multiples. |
| IK — amortissement λ | `trajectory.ik.damping` |  | 0 … 1 | 0,02 | Facteur d’amortissement des moindres carrés (robustesse près des singularités). |
| IK — itérations max | `trajectory.ik.maxIter` |  | 5 … 2000 | 150 | Nombre maximal d’itérations du solveur numérique. |
| IK — tolérance position | `trajectory.ik.tolPos` | mm | 0 … 10 | 0,01 |  |
| IK — tolérance orientation | `trajectory.ik.tolRot` | ° | 0 … 5,73 | 0,01 |  |
| IK — poids orientation | `trajectory.ik.orientationWeight` | m | 0,001 … 2 | 0,15 | Longueur caractéristique (m/rad) équilibrant erreurs de position et d’orientation. |
| Jog — pas linéaire | `trajectory.jog.linStep` | mm | 0,1 … 100 | 5 |  |
| Jog — pas angulaire | `trajectory.jog.angStep` | ° | 0,06 … 57,3 | 5 |  |
| Jog — vitesse linéaire | `trajectory.jog.linSpeed` | mm/s | 1 … 1000 | 50 | Vitesse du jog cartésien continu. |
| Jog — vitesse articulaire | `trajectory.jog.jointSpeed` | °/s | 0,6 … 286,5 | 30 |  |

## Pince / outil

Pince parallèle à crémaillère entraînée par servomoteur (MG996R par défaut).

| Paramètre | Clé | Unité | Plage | Valeur ORION-6 MAKER | Rôle |
|---|---|---|---|---|---|
| Type | `gripper.type` |  | `parallel`, `vacuum`, `none` | Pince parallèle (servo) |  |
| Ouverture max | `gripper.strokeMax` | mm | 1 … 300 | 50 | Écartement maximal des doigts. |
| Vitesse des doigts | `gripper.speed` | mm/s | 1 … 1000 | 40 |  |
| Force de serrage | `gripper.force` | N | 0 … 500 | 25 | Force nominale (servo en butée sur l’objet). |
| Longueur des doigts | `gripper.fingerLength` | mm | 5 … 300 | 55 |  |
| Servo — impulsion fermée | `gripper.servoMinUs` |  | 400 … 2600 | 900 | Largeur d’impulsion PWM (µs) pince fermée. |
| Servo — impulsion ouverte | `gripper.servoMaxUs` |  | 400 … 2600 | 2100 | Largeur d’impulsion PWM (µs) pince ouverte. |

## Sécurité

Surveillance des collisions, vitesses réduites et chien de garde de communication.

| Paramètre | Clé | Unité | Plage | Valeur ORION-6 MAKER | Rôle |
|---|---|---|---|---|---|
| Détection de collision (couple) | `safety.collisionDetection` |  | oui / non | oui | Compare le couple mesuré/commandé au couple prédit par le modèle ; au-delà du seuil → arrêt. |
| Seuil de collision | `safety.collisionThreshold` | N·m | 0,05 … 50 | 3 | Écart de couple (N·m, côté articulation) déclenchant l’arrêt. |
| Auto-collision | `safety.selfCollision` |  | oui / non | oui | Vérifie les collisions entre segments non adjacents (modèle en capsules). |
| Collision avec la table | `safety.floorCollision` |  | oui / non | oui | Vérifie que le bras et l’outil restent au-dessus du plan de travail. |
| Marge de collision | `safety.capsuleMargin` | mm | 0 … 50 | 4 | Distance minimale tolérée entre capsules. |
| Vitesse réduite (mode manuel) | `safety.reducedSpeed` | % | 1 … 100 | 25 | Limite de vitesse en mode apprentissage (≈ 250 mm/s en industrie). |
| Vitesse TCP collaborative | `safety.collabTcpSpeed` | mm/s | 10 … 2000 | 250 | Vitesse TCP maximale quand le mode collaboratif est actif. |
| Chien de garde (ms) | `safety.watchdogMs` |  | 20 … 5000 | 250 | Sans nouvelle consigne pendant ce délai, le robot freine et s’arrête (flux temps réel). |
| Marge butées logicielles | `safety.softLimitMargin` | ° | 0 … 11,46 | 1 | Marge de décélération avant les butées. |

## Simulation

Intégration numérique et effets physiques simulés.

| Paramètre | Clé | Unité | Plage | Valeur ORION-6 MAKER | Rôle |
|---|---|---|---|---|---|
| Pas physique | `simulation.dt` | ms | 0,05 … 5 | 0,25 | Pas d’intégration (intégrateur semi-implicite). 0,25 ms reproduit fidèlement la raideur magnétique des pas-à-pas. |
| Facteur temps réel | `simulation.realtimeFactor` |  | 0,05 … 10 | 1 | 1 = temps réel ; < 1 ralenti ; > 1 accéléré. |
| Frottements | `simulation.enableFriction` |  | oui / non | oui |  |
| Jeu des réducteurs | `simulation.enableBacklash` |  | oui / non | oui |  |
| Perte de pas (pas-à-pas) | `simulation.enableStepLoss` |  | oui / non | oui | Modèle physique couple-angle : si la charge dépasse le couple disponible, le rotor décroche. |
| Bruit de mesure | `simulation.sensorNoise` | ° | 0 … 0,57 | 0 | Écart-type du bruit ajouté aux positions mesurées. |
| Fréquence d’enregistrement | `simulation.recordHz` | Hz | 10 … 2000 | 200 | Échantillonnage des courbes et exports CSV. |
| Fenêtre des courbes | `simulation.plotWindow` | s | 1 … 120 | 10 |  |

## Matériel & firmware

Brochage, drivers, prise d’origine. Exporté dans firmware/orion_fw/src/orion_config.h.

| Paramètre | Clé | Unité | Plage | Valeur ORION-6 MAKER | Rôle |
|---|---|---|---|---|---|
| Contrôleur | `hardware.controller` |  | `teensy41`, `mit_can_bridge` | Teensy 4.1 (recommandé) |  *PRO : Teensy 4.1 + CAN (moteurs mode MIT)* |
| Largeur impulsion STEP | `hardware.stepPulse` | µs | 1 … 100 | 3 | DM542T : ≥ 2,5 µs. TMC2209 : ≥ 0,1 µs. |
| Délai DIR → STEP | `hardware.dirSetup` | µs | 0 … 100 | 6 | Temps d’établissement de la direction avant l’impulsion (DM542T : ≥ 5 µs). |
| ENABLE actif à l’état bas | `hardware.enableActiveLow` |  | oui / non | oui | Dépend du câblage des drivers (optocoupleurs DM542T : ENA+ au 5 V, ENA− piloté). |
| Fréquence de flux USB | `hardware.streamHz` | Hz | 10 … 1000 | 200 | Fréquence d’envoi des consignes articulaires en mode jumeau numérique (streaming). |
| Lissage du flux (retard) | `hardware.streamDelay` | ms | 0 … 400 | 40 | Avance du tampon d’interpolation du firmware : absorbe la gigue USB/navigateur. Plus grand = plus lisse mais plus de retard (40 ms conseillé). |
| Débit CAN | `hardware.canBitrate` | kbit/s | 125 … 1000 | 1000 | Débit du bus CAN (mode MIT) — 1 Mbit/s en standard. |
| Fréquence de commande CAN (MIT) | `hardware.mitCtrlHz` | Hz | 50 … 1000 | 400 | Trames MIT envoyées par moteur et par seconde. Chaque trame reçoit une réponse : 6 moteurs à 400 Hz ≈ 60 % d’un bus à 1 Mbit/s. |
| Délai max. sans retour CAN | `hardware.feedbackTimeout` | ms | 10 … 1000 | 50 | Au-delà, le pont passe en défaut et amortit tous les axes. |
| Température moteur max. | `hardware.maxMotorTemp` |  | 40 … 120 | 85 | °C (MOSFET ou bobinage) avant mise en défaut. |
| **Brochage Teensy** — tableau par articulation (J1 · J2 · … · J6) | `hardware.pins[i]` | | | |  |
| ↳ STEP | `.step` |  | 0 … 54 | 2 · 4 · 6 · 8 · 10 · 12 |  |
| ↳ DIR | `.dir` |  | 0 … 54 | 3 · 5 · 7 · 9 · 11 · 14 |  |
| ↳ Capteur d’origine | `.limit` |  | 0 … 54 | 24 · 25 · 26 · 27 · 28 · 29 |  |
| ↳ Inverser DIR | `.invertDir` |  | oui / non | non (tous) | Inverse le sens de rotation physique (câblage moteur). |
| ↳ Capteur actif bas | `.limitActiveLow` |  | oui / non | oui (tous) | Capteur NPN/interrupteur vers la masse avec pull-up : actif à l’état bas. |
| Broche ENABLE commune | `hardware.enablePin` |  | 0 … 54 | 15 |  |
| Broche arrêt d’urgence | `hardware.estopPin` |  | 0 … 54 | 30 |  |
| Broche servo pince | `hardware.gripperPin` |  | 0 … 54 | 33 |  |
| **Prise d’origine** — tableau par articulation (J1 · J2 · … · J6) | `hardware.homing[i]` | | | |  |
| ↳ Active | `.enabled` |  | oui / non | oui (tous) |  |
| ↳ Sens de recherche | `.direction` |  | -1 … 1 | -1 · -1 · 1 · -1 · -1 · -1 | −1 ou +1 : sens de déplacement vers le capteur. |
| ↳ Vitesse de recherche | `.speed` | °/s | 0,1 … 114,6 | 20 · 15 · 15 · 30 · 30 · 30 |  |
| ↳ Vitesse d’approche fine | `.slowSpeed` | °/s | 0,1 … 57,3 | 2 · 2 · 2 · 3 · 3 · 3 |  |
| ↳ Recul | `.backoff` | ° | 0 … 28,65 | 4 · 4 · 4 · 5 · 5 · 5 |  |
| ↳ Position du capteur | `.switchPosition` | ° | -360 … 360 | -172 · -133 · 62 · -172 · -117 · -182 | Valeur articulaire q au point de déclenchement du capteur (à calibrer). |
| ↳ Ordre | `.order` |  | 1 … 12 | 6 · 5 · 4 · 3 · 1 · 2 | Ordre de prise d’origine (poignet d’abord recommandé). |

## Poses nommées

Positions articulaires de référence utilisables dans les programmes (MoveJ Home…).

| Paramètre | Clé | Unité | Plage | Valeur ORION-6 MAKER | Rôle |
|---|---|---|---|---|---|
| Home (travail) | `poses.home` | ° |  | 0 / 0 / 0 / 0 / 90 / 0 | Pose de départ des programmes. |
| Repos (transport) | `poses.rest` | ° |  | 0 / -10 / 55 / 0 / 35 / 0 | Pose repliée, compacte et stable hors tension. |
| Zéro mécanique | `poses.zero` | ° |  | 0 / 0 / 0 / 0 / 0 / 0 | Toutes les articulations à 0 (vérification de la table DH). |

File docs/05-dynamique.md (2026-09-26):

# 5. Dynamique et modèles d’actionneurs

Code : `studio/core/dynamics.js` (modèle rigide), `studio/core/actuators.js` (moteurs, réducteurs, frottements),
`studio/core/simulator.js` (intégration temps réel). Tests : `tests/dynamics.test.mjs`.

Le simulateur d’ORION Studio a un objectif précis : **reproduire les défauts qui comptent sur un bras imprimé**, pour
qu’un réglage validé à l’écran se comporte de la même façon sur le vrai robot. Ces défauts sont :

- la flexibilité et le jeu des réducteurs ;
- le frottement ;
- la chute de couple des pas-à-pas avec la vitesse ;
- la **perte de pas** ;
- la saturation de couple.

## Modèle rigide : τ = M(q)·q̈ + C(q, q̇)·q̇ + g(q)

- **Newton-Euler récursif (RNEA)** dans le repère monde, valable en DH standard comme en DH modifiée. Une passe
  aller propage les vitesses et accélérations des segments ; une passe retour propage les efforts. Le résultat donne les
  couples articulaires, mais aussi les **efforts dans chaque liaison** (force axiale et radiale, moment de basculement),
  affichés dans *Analyse* pour choisir les roulements.
- **Matrice d’inertie M(q)** : obtenue colonne par colonne avec le RNEA (q̇ = 0, g = 0, q̈ = eᵢ). Elle est symétrique
  définie positive, ce que vérifie une factorisation de Cholesky dans les tests.
- **Gravité g(q)** : RNEA avec q̇ = q̈ = 0. Un test compare le couple de J2 au moment des poids des segments 2 à 6.
- **Dynamique directe** : q̈ = M⁻¹·(τ − C·q̇ − g − τ_frottement + Jᵀ·F_ext). Sans frottement, l’énergie est conservée
  (dérive < 0,01 % après 1 000 pas RK4, vérifié par test).
- **Charge utile** : masse ponctuelle, décalage et inertie propre réglables. Elle s’ajoute au segment 6. Une pièce saisie
  par la pince en simulation modifie automatiquement la charge.

### Paramètres inertiels

Pour chaque segment : masse, centre de masse (repère DH du segment), tenseur d’inertie au centre de masse (Ixx, Iyy, Izz,
Ixy, Ixz, Iyz). Les valeurs par défaut sont **calculées par la CAO** (`npm run build:cad`) :

- pièces imprimées : volume × densité (1,24 g/cm³, valeur type PLA/PETG) × taux de remplissage estimé ;
- moteurs, roulements, tubes aluminium, goupilles et visserie : masses réelles.

Ces valeurs dépendent du matériau et des réglages d’impression réels. Pesez les segments imprimés et corrigez les masses
dans *Paramètres → Dynamique* : la compensation de gravité (modes MIT, PID, impédance) et le dimensionnement en dépendent
directement.

## Modèle d’actionneur : l’articulation flexible

Chaque axe est modélisé comme une **articulation flexible** (modèle de Spong) :

```
 moteur (inertie ramenée N²·J_rotor)  ──[ réducteur : raideur k, amortissement c, jeu b ]──  segment (dynamique rigide)
         θ_rotor (ramené en sortie)                                                          q
```

- **Inertie rotor ramenée** : N²·J_rotor. Elle domine souvent l’inertie vue par l’axe : pour J2 (NEMA23 76 mm, 30:1),
  30² × 480 g·cm² = 0,043 kg·m², soit une valeur **comparable à l’inertie du bras** lui-même. Elle entre dans
  l’auto-réglage des gains.
- **Transmission** : τ_t = k·dz(θ_rotor − q) + c·(ω_rotor − q̇)·contact. dz est une **zone morte lissée** de largeur
  égale au jeu b :
  dz(δ) = s·[softplus((δ − b/2)/s) − softplus((−δ − b/2)/s)], avec s = b/24.
  Ce lissage garde un modèle dérivable, donc stable à l’intégration implicite, tout en reproduisant le « flottement »
  dans le jeu et le choc de reprise.
- **Valeurs par défaut** (MAKER) :
  - raideur : 2 500 à 4 000 N·m/rad pour J1–J3, 600 à 800 N·m/rad pour le poignet ;
  - jeu : 0,2 à 0,4°.

  Ce sont des estimations pour des cycloïdes en PETG à goupilles acier. **Mesurez-les** sur vos modules (voir
  [12. Calibration](12-calibration.md)).

### Pas-à-pas : couple magnétique et perte de pas

Un moteur hybride 1,8° a **Nr = 50 dents** (4 pas entiers par période électrique). Son couple magnétique rappelle le
rotor vers la position commandée :

τ_moteur = T(ω)·sin(Nr·(θ_commande − θ_rotor))

- **T(ω)** est le couple de décrochage : environ 85 % du couple de maintien, au courant réglé du driver. Au-delà de la
  **vitesse de coin** ωc = V / (I·Nr·L + k_e), l’inductance empêche le courant de s’établir et le couple décroît en
  1/ω.
  - V : tension d’alimentation ;
  - I : courant réglé ;
  - L : inductance de phase ;
  - k_e ≈ couple de maintien / courant nominal.

  C’est pourquoi une alimentation **36 V ou plus** est recommandée.
- **Perte de pas** : si la charge écarte le rotor de plus d’une demi-période électrique (2 pas entiers) de sa consigne,
  il saute sur la dent suivante. Le simulateur détecte ce saut et compte les pas perdus (événement *perte de pas* dans le
  journal, compteur par axe). La position réelle reste décalée, exactement comme sur le vrai robot en boucle ouverte.
- **Micro-pas** : la consigne est quantifiée à la résolution micro-pas en sortie, par exemple 0,0045° pour J1 à 16
  micro-pas et 25:1.

### Brushless QDD (mode MIT) et servos

L’actionneur est une source de couple limitée par une **droite couple-vitesse** : couple crête à vitesse nulle, nul à
la vitesse maximale. En freinage, le couple crête reste disponible. Le couple commandé vient soit de la loi MIT
(Kp, Kd, τff), évaluée **en continu** comme dans le driver du moteur, soit du correcteur choisi.

## Frottements

Côté sortie de chaque axe, modèle de **Stribeck lissé** :

τ_f(v) = [F_c + (F_s − F_c)·exp(−(v/v_s)²)]·tanh(v/ε) + b·v

- F_c : frottement sec (Coulomb) ;
- F_s : adhérence (stiction) ;
- v_s : vitesse de Stribeck ;
- b : frottement visqueux ;
- ε = 2 mrad/s : lissage autour de v = 0.

Les correcteurs peuvent anticiper le frottement avec un estimateur sans le terme d’adhérence (option *anticipation
frottements*).

## Intégration numérique (temps réel)

L’état comprend, pour chaque axe, la position et la vitesse du segment (q, v) et celles du rotor ramené (θ, u).

Les raideurs magnétiques des pas-à-pas et les raideurs de transmission rendent le système **raide** : un Euler explicite
exigerait un pas inférieur à 10 µs. Le simulateur utilise donc un **Euler linéairement implicite** et élimine les
rotors par **complément de Schur** :

```
(Ja + α + β)·Δu − (α − γ)·Δv = dt·(τm − τt)
[M + diag(α + δ − α(α−γ)/s)]·Δv = dt·(τt − b − τf + τext) + diag(α/s)·r
```

- α = dt·(dt·k + c) : transmission ;
- β : raideur et amortissement propres du moteur ;
- γ : PD continu du mode MIT ;
- δ : frottement visqueux et butées.

Résultats :

- **pas de temps 0,25 ms** par défaut (réglable), stable même avec le jeu et la perte de pas ;
- matrice d’inertie recalculée à 1 kHz ;
- **6 à 9 fois plus rapide que le temps réel** dans un navigateur courant ;
- le paramètre *Facteur temps réel* ralentit ou accélère la simulation ;
- correcteurs échantillonnés à leur propre fréquence (*Commande → Fréquence de boucle*), avec bloqueur d’ordre zéro,
  comme sur un vrai contrôleur ;
- bruit de mesure optionnel (*Simulation → Bruit de mesure*) pour tester la robustesse des gains.

## Détection de collision (simulation)

- **Auto-collision et table** : les 53 capsules extraites de la CAO sont testées sur la **consigne**, à chaque cycle de
  commande. Si un contact est prévu pendant un mouvement, le simulateur déclenche un *arrêt de protection* signalé dans
  le journal. L’affichage des capsules en contact (vue 3D) est rafraîchi à 4 Hz.
- **Choc** (option *Détection de collision*) : le simulateur calcule un résidu r = τ_transmis − τ̂_frottement −
  (M̂·q̈ + b̂), qui estime le couple extérieur. Ce résidu est filtré sur environ 20 ms. S’il dépasse le *seuil de
  collision* (N·m), le mouvement s’arrête. Poussez le bras (`Maj` + glisser) pour l’essayer.

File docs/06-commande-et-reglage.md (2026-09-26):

# 6. Commande et réglage

Code : `studio/core/control.js` (lois de commande, auto-réglage), `studio/core/trajectory.js` (profils, MoveJ/L/C,
lissage), firmware `firmware/orion_fw` (pas-à-pas) et `firmware/mit_bridge` (mode MIT).

Tous les réglages se font dans **Paramètres → Commande** et **Paramètres → Limites / Trajectoires**. On les teste
immédiatement en simulation : onglets *Analyse → Réponse indicielle* et *Courbes → Erreur de suivi / Charge moteur*.

## Vue d’ensemble des modes

| Mode | Loi de commande | Quand l’utiliser |
|---|---|---|
| **Pas-à-pas** | position commandée micro-pas par micro-pas, sans retour | ORION-6 MAKER (le vrai robot) |
| **PID** | τ = Kp·e + Ki·∫e + Kd·(q̇* − q̇) + τ_ff | servos à codeur, étude des gains |
| **Mode MIT** | τ = Kp·(p* − p) + Kd·(v* − v) + τff | ORION-6 PRO, moteurs Damiao/CubeMars/MIT Cheetah |
| **Couple calculé** | τ = M̂(q)·(q̈* + ω²·e + 2ζω·ė) + b̂(q, q̇) | suivi précis à grande vitesse |
| **Impédance** | τ = Jᵀ·(K·Δx + D·Δẋ) + ĝ(q) − D_null·q̇ | contact, insertion, interaction humaine |
| **Compensation de gravité** | τ = ĝ(q) − D_null·q̇ | guidage à la main, apprentissage |

L’anticipation τ_ff peut contenir trois termes, cumulables et activables séparément :

- la **gravité** ĝ(q) ;
- l’**inertie** M̂(q)·q̈* ;
- le **frottement** (Coulomb + visqueux dans le sens de q̇*).

Les grandeurs « chapeau » (M̂, ĝ, b̂) viennent du modèle dynamique. Le paramètre *Erreur de modèle* le fausse
volontairement pour tester la robustesse.

## Le mode MIT en détail

Le mode MIT vient du contrôleur de moteur développé par Ben Katz pour le robot **Mini Cheetah** du MIT. De nombreux
moteurs QDD l’ont repris depuis (Damiao, CubeMars, MyActuator…). Le driver du moteur exécute à haute fréquence
(plusieurs kHz, dans sa boucle de courant) :

**τ = Kp·(p* − p) + Kd·(v* − v) + τff**

Le contrôleur maître envoie, à 200 Hz ou plus, une trame CAN de 8 octets avec les cinq consignes p*, v*, Kp, Kd et τff.
La boucle de raideur et d’amortissement est donc **fermée dans le moteur**, sans retard de bus. Le maître ne s’occupe
que de la trajectoire et du modèle (compensation de gravité, inertie).

Avec un seul format, on obtient ainsi plusieurs comportements :

| Réglage | Comportement |
|---|---|
| Kp élevé, Kd moyen, τff = ĝ(q) | asservissement de position raide, qui tient la charge sans erreur statique |
| Kp faible, Kd faible, τff = ĝ(q) | bras **compliant** : suit la trajectoire mais cède aux chocs |
| Kp = 0, Kd faible, τff = ĝ(q) | **gravité compensée** : le bras flotte, on le guide à la main |
| Kp = 0, Kd > 0, τff = 0 | **amortissement** : état de sécurité (défaut, perte de communication) |

C’est exactement l’architecture des bras de recherche de type **YAM** (i2rt) : commande PD + compensation de gravité,
moteurs DM sur bus CAN à 1 Mbit/s, passage en amortissement en cas de perte des commandes.

### Encodage des trames (identique dans ORION Studio et dans le firmware)

| Octets | Contenu | Bits | Plage |
|---|---|---|---|
| 0–1 | p* | 16 | ±P_MAX (12,5 rad) |
| 2 + ½ octet 3 | v* | 12 | ±V_MAX (8 rad/s pour DM4340, 30 rad/s pour DM4310) |
| ½ octet 3 + 4 | Kp | 12 | 0 … KP_MAX (500) |
| 5 + ½ octet 6 | Kd | 12 | 0 … KD_MAX (5) |
| ½ octet 6 + 7 | τff | 12 | ±T_MAX (28 N·m pour DM4340, 10 N·m pour DM4310) |

La conversion est linéaire : u = round((x − min)·(2ⁿ − 1)/(max − min)). **Les plages doivent correspondre aux réglages
du moteur**, faits avec l’outil du fabricant. Sinon les consignes sont fausses d’un facteur d’échelle. Le retour du
moteur (format Damiao) donne l’identifiant, le code d’erreur, p, v, τ et les températures du MOSFET et du bobinage.

### Gains MIT par défaut (ORION-6 PRO)

| | J1 | J2 | J3 | J4 | J5 | J6 |
|---|---|---|---|---|---|---|
| Kp (N·m/rad) | 80 | 120 | 80 | 30 | 25 | 15 |
| Kd (N·m·s/rad) | 2,5 | 3,5 | 2,5 | 1,0 | 0,8 | 0,5 |
| Kd amortissement (défaut) | 5 | 5 | 5 | 2 | 1,6 | 1 |

Ordre de grandeur : pour J2 avec Kp = 120 N·m/rad, une erreur de 1° produit 2,1 N·m. Sans compensation de gravité, les
10,7 N·m de gravité maximale de J2 (bras tendu, avec la charge nominale) feraient donc fléchir le bras d’environ 5°.
Avec τff = ĝ(q), l’erreur statique ne dépend plus que de l’erreur du modèle de masse. La marge de couple de la variante
PRO est de ×1,68 sur J2 et ×3,8 ou plus sur les autres axes (27 N·m crête pour les DM4340, 7 N·m pour les DM4310).

## Réglage : méthode pas à pas

### 1. Vérifier le modèle

- Pose *Zéro* : bras vertical, avant-bras horizontal. Activez les *Repères DH* pour contrôler les axes.
- Masses : pesez vos segments imprimés et corrigez *Dynamique → masses*. Une compensation de gravité juste en dépend.
- *Analyse → Dimensionnement* : toutes les marges doivent être au moins *Juste* (≥ ×1,1), idéalement *OK* (≥ ×1,5).
  Sinon, trois leviers :
  - réduire *Accélération max* et *Jerk max* ;
  - augmenter le courant du driver (sans dépasser le courant nominal du moteur) ;
  - changer de moteur ou de réduction.

### 2. Auto-réglage (placement de pôles)

*Analyse → Auto-régler les gains* calcule pour chaque axe, dans la pose courante :

- **J** : inertie vue par l’axe = M_ii(q) + N²·J_rotor ;
- **Kp = J·ω²**, **Kd = 2·ζ·J·ω**, **Ki = Kp·ω/10**, avec ω = 2π·f_bande ;
- les gains MIT : **Kp_MIT = min(Kp, KP_MAX)** et **Kd_MIT = min(Kd, KD_MAX)**.

Les valeurs par défaut sont une bande passante de **8 Hz** et **ζ = 0,9** : réponse rapide, dépassement quasi nul.

- Augmentez la bande passante pour plus de raideur et un meilleur suivi, jusqu’à l’apparition d’oscillations. Celles-ci
  viennent du jeu, de la flexibilité des réducteurs imprimés et du retard d’échantillonnage.
- Règle pratique : **f_bande < f_résonance/3**. La fréquence de résonance vaut f_rés = √(k/J)/2π, avec k la raideur du
  réducteur.
- Avec des cycloïdes imprimées (k ≈ 2 500 N·m/rad), on obtient typiquement f_rés ≈ 15–40 Hz selon la pose. D’où une
  bande passante de 5 à 10 Hz.

### 3. Réponse indicielle

*Analyse → Réponse indicielle* : un échelon de 2° est appliqué sur un axe dans un simulateur séparé. Le robot affiché
n’est pas perturbé. Lisez :

| Symptôme | Cause probable | Correction |
|---|---|---|
| dépassement > 20 %, oscillation amortie | Kd trop faible ou Kp trop fort | augmenter ζ (ou Kd) |
| oscillation entretenue (« pompage ») autour de la consigne | jeu du réducteur + Ki | réduire Ki, ajouter une *zone morte* ≈ jeu/2 |
| montée lente, erreur finale | Kp faible, gravité non compensée | activer l’*anticipation gravité*, augmenter Kp |
| vibration haute fréquence | Kd bruité, fréquence de boucle basse | baisser le *filtre dérivée*, augmenter la *fréquence de boucle* |
| saturation du couple (*Courbes → Couples*) | échelon trop grand pour les gains | normal sur grand échelon, sinon réduire les gains |

### 4. Suivi de trajectoire

Lancez l’exemple *Test de répétabilité* et observez *Courbes → Erreur de suivi*.

- Activez l’**anticipation d’inertie** (M̂·q̈*) : l’erreur de suivi chute d’un facteur 5 à 10 en mouvement rapide.
- En pas-à-pas, surveillez la **Charge moteur**. Au-delà de 70–80 % du couple disponible, le risque de perte de pas
  devient réel à cause des variations de frottement et de l’usure. Réduisez l’accélération ou le jerk, ou la vitesse si
  la charge monte avec elle (chute de couple au-delà de la vitesse de coin).

### 5. Réglage spécifique ORION-6 MAKER (pas-à-pas)

Il n’y a pas de gains à régler : la précision vient du **dimensionnement** et des **profils**.

| Paramètre | Conseil |
|---|---|
| Profil | **courbe en S** : jerk limité, beaucoup moins de vibrations et de pertes de pas qu’un trapèze |
| Micro-pas | 16 (bon compromis douceur / fréquence de pas ; 45 kpas/s max par axe dans le firmware) |
| Courant de marche | 80 à 100 % du nominal ; au-delà, le moteur chauffe sans gain de couple |
| Alimentation | 36 V ou plus pour garder du couple à vitesse élevée (vitesse de coin ∝ V) |
| Vitesse max | *Analyse → Dimensionnement* : survolez un axe pour voir la vitesse moteur et la vitesse de coin |
| Accélération / jerk | commencez à 50 % et augmentez tant que la charge moteur reste < 70 % |

### 6. Réglage spécifique ORION-6 PRO (mode MIT)

1. Réglez sur chaque moteur, avec l’outil du fabricant, le **mode MIT**, l’identifiant CAN (1–6), l’identifiant maître
   et les plages P_MAX, V_MAX et T_MAX. Reportez les mêmes plages dans *Actionneurs* (P_MAX…KD_MAX).
2. Commencez avec des gains **divisés par 2**, sans charge. Activez *Anticipation gravité* : le préréglage PRO la fournit
   dans τff.
3. Mode *Compensation de gravité* : le bras doit flotter. S’il tombe ou remonte, corrigez les masses et les centres de
   masse du segment concerné.
4. Remontez Kp jusqu’aux valeurs par défaut en contrôlant la *Réponse indicielle*. Kd doit donner ζ ≈ 0,7–1.
5. **Surveillez les températures** : la commande `FB` du pont affiche les températures MOSFET et bobinage. Un Kp élevé
   avec une erreur statique non compensée (masse fausse) fait chauffer le moteur en permanence.

## Trajectoires

### Profils de vitesse (MoveJ et re-temporisation)

| Profil | Continuité | Durée pour Δq, v, a donnés | Usage |
|---|---|---|---|
| Trapèze | accélération discontinue | la plus courte | robots rigides |
| **Courbe en S** (7 phases) | accélération continue, jerk borné | un peu plus longue (dépend du jerk) | **par défaut**, réducteurs imprimés |
| Quintique | jerk continu | plus longue | mouvements très doux |
| Cycloïdal | accélération sinusoïdale | plus longue | mouvements « organiques » |

- **MoveJ** synchronise tous les axes : chacun arrive en même temps, avec un profil homothétique. L’axe le plus
  contraint fixe la durée.
- **MoveL / MoveC** : trajectoire cartésienne (ligne ou arc par 3 points) avec interpolation d’orientation SLERP.
  Elle est discrétisée à *Échantillonnage cartésien* (250 Hz par défaut) par le modèle inverse, puis
  **re-temporisée** si une vitesse ou une accélération articulaire serait dépassée (près d’une singularité, par exemple).
- **Lissage (fly-by)** : avec une zone `z` > 0, le mouvement suivant commence avant la fin du précédent, par
  superposition des deux profils. Le robot ne s’arrête pas aux points intermédiaires.
- **Arrêt contrôlé** (touche `Espace`) : freinage à la décélération maximale le long de la trajectoire.
  **Arrêt d’urgence** (bouton rouge *STOP* ou `Échap`) : coupure immédiate du couple.

### Limites par défaut (ORION-6 MAKER)

| | J1 | J2 | J3 | J4 | J5 | J6 |
|---|---|---|---|---|---|---|
| vitesse (°/s) | 120 | 90 | 110 | 170 | 170 | 200 |
| accélération (°/s²) | 300 | 200 | 300 | 600 | 600 | 700 |
| jerk (°/s³) | 3 000 | 2 000 | 3 000 | 6 000 | 6 000 | 7 000 |

Côté cartésien : 250 mm/s et 1 m/s² au TCP, 90°/s en rotation. Le potentiomètre de *Vitesse* de la barre du haut
multiplie toutes les vitesses. Il vaut 50 % au démarrage.

## Côté firmware

- **Pas-à-pas** (`orion_fw`) :
  - `MJ` exécute un profil trapézoïdal synchronisé 25/50/25 % ;
  - `SP` reçoit le flux de consignes du jumeau numérique ;
  - un limiteur de vitesse et d’accélération ultime, qui ne dépasse jamais la cible, protège les moteurs contre toute
    consigne incohérente.
- **Pont MIT** (`mit_bridge`) :
  - envoi des trames à 400 Hz par moteur (réglable) ;
  - raccord progressif de 300 ms au démarrage d’un flux ;
  - maintien avec le dernier couple de gravité si les consignes s’interrompent (chien de garde) ;
  - amortissement (Kp = 0) en cas de défaut moteur.

Voir [11. Firmware et protocole](11-firmware-protocole.md).

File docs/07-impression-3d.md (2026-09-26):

<!-- FICHIER GÉNÉRÉ par tools/gen-docs.mjs depuis hardware/parts.json — ne pas modifier à la main. -->

# 7. Impression 3D des pièces

Toutes les pièces sont générées par la CAO paramétrique (`npm run build:cad`) et se trouvent dans
[`hardware/stl/`](../hardware/stl/). Elles tiennent sur un plateau **220 × 220 × 250 mm** (vérifié automatiquement)
et sont déjà **orientées pour l’impression** (face d’appui en Z = 0, sans supports sauf mention).

**Total : 37 fichiers STL, 58 pièces, ≈ 2,2 kg de matière** (+ 25 % de marge pour les purges et
supports éventuels).

> ⚠️ **Imprimez d’abord `tolerance-test.stl`.** Il contient les alésages de goupilles Ø3/Ø4/Ø5, un logement de
> roulement 688, un logement d’insert M3 et une fente de méplat. Si les goupilles n’entrent pas à la main (ajustement
> glissant) ou flottent, corrigez le paramètre *Jeu d’impression* (CAO) ou la compensation XY de votre trancheur **avant**
> d’imprimer les réducteurs. Ce projet n’a pas encore été validé sur un exemplaire physique.

## Réglages conseillés

| Réglage | Pièces de structure | Réducteurs (disques, cames, flasques) | Patins de pince |
|---|---|---|---|
| Matériau | PETG (ou PLA+, ASA près des moteurs chauds) | PETG ou PA-CF si disponible | TPU 95A |
| Buse / couche | 0,4 mm / 0,2 mm | 0,4 mm / **0,15 mm** | 0,4 mm / 0,2 mm |
| Parois | 4 périmètres | **5 périmètres** | 3 |
| Remplissage | voir tableau (gyroïde) | voir tableau (100 % pour cames et disques) | 100 % |
| Couches pleines dessus/dessous | 5 / 5 | 6 / 6 | 4 / 4 |
| Vitesse | 60–100 mm/s | **≤ 50 mm/s** (précision des profils) | 25 mm/s |
| Compensation XY | selon le test de tolérances | idem (profils critiques) | — |
| Supports | non (sauf note) | non | non |

- **Retrait / dilatation** : laissez refroidir les pièces sur le plateau (PETG) pour limiter le gauchissement des carters.
- **Inserts filetés** : fer à 230–245 °C (PETG), poussez l’insert bien perpendiculairement ; laissez refroidir avant de
  visser. Les logements font Ø4,0 mm (M3) et Ø5,6 mm (M4), profondeur 6 mm.
- **Goupilles** : les alésages des couronnes sont prévus pour des goupilles acier trempé ISO 8734 enfoncées à la presse
  (étau). Une goutte de colle frein/époxy est inutile si l’ajustement est correct.
- **Disques cycloïdaux** : ébavurez l’arête inférieure (« pied d’éléphant ») au cutter ; c’est la cause n°1 de points
  durs. Les deux disques d’un même module (A et B) sont décalés d’un demi-lobe : ils ne sont **pas** interchangeables.
- **Cames** : 100 % de remplissage, méplat orienté vers le haut ; vérifiez l’excentricité au comparateur si possible.
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

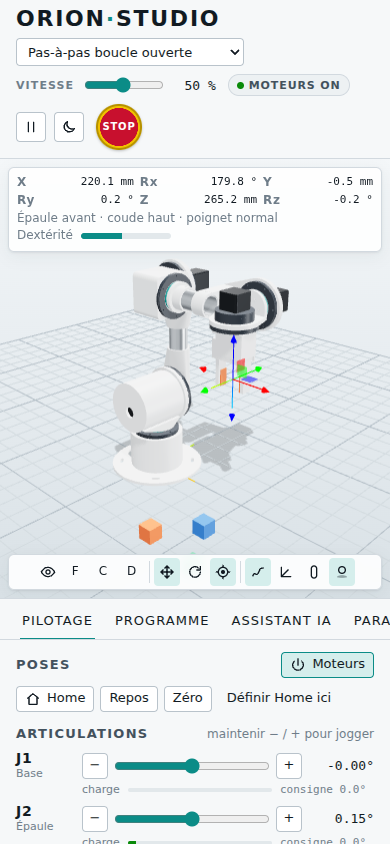
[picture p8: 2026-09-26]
docs/img/studio-mobile.png

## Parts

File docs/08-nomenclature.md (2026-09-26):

<!-- FICHIER GÉNÉRÉ par tools/gen-docs.mjs depuis hardware/bom.csv — ne pas modifier à la main. -->

# 8. Nomenclature (ORION-6 MAKER)

Nomenclature complète générée à partir de la CAO (`npm run build:cad` → [`hardware/bom.csv`](../hardware/bom.csv),
format tableur, séparateur « ; »). Les prix sont **indicatifs** (achats à l’unité chez des revendeurs grand public,
2026) : ils varient fortement selon les fournisseurs et les quantités.

**Coût matériel estimé : ≈ 581 €** (hors imprimante, outillage et frais de port).

| Poste | Montant |
|---|---|
| Moteurs | 98 € |
| Roulements | 71 € |
| Goupilles | 16 € |
| Structure | 12 € |
| Pince | 7 € |
| Visserie | 10 € |
| Inserts | 8 € |
| Consommables | 76 € |
| Électronique | 284 € |
| **Total** | **581 €** |

### Moteurs

| Référence | Désignation | Quantité | Prix unitaire indicatif | Sous-total |
|---|---|---|---|---|
| NEMA17-48 | Moteur pas-à-pas NEMA17 48 mm, 1,8°/pas (ex. 0.59 N·m) | 1 pce | 14 € | 14 € |
| NEMA23-76 | Moteur pas-à-pas NEMA23 76 mm, 1,8°/pas (ex. 1.89 N·m) | 1 pce | 32 € | 32 € |
| NEMA17-60 | Moteur pas-à-pas NEMA17 60 mm, 1,8°/pas (ex. 0.65 N·m) | 1 pce | 17 € | 17 € |
| NEMA17-40 | Moteur pas-à-pas NEMA17 40 mm, 1,8°/pas (ex. 0.42 N·m) | 2 pce | 12 € | 24 € |
| NEMA17-34 | Moteur pas-à-pas NEMA17 34 mm, 1,8°/pas (ex. 0.28 N·m) | 1 pce | 11 € | 11 € |
| | **Sous-total moteurs** | | | **98 €** |

### Roulements

| Référence | Désignation | Quantité | Prix unitaire indicatif | Sous-total |
|---|---|---|---|---|
| 6811 | Roulement à billes à section mince 6811 2RS | 2 pce | 8 € | 16 € |
| 6803 | Roulement à billes 6803 2RS (came) | 4 pce | 1,6 € | 6,4 € |
| 688 | Roulement 688 2RS (8×16×5, support de came) | 6 pce | 0,8 € | 4,8 € |
| 6814 | Roulement à billes à section mince 6814 2RS | 1 pce | 12 € | 12 € |
| 6804 | Roulement à billes 6804 2RS (came) | 2 pce | 2,2 € | 4,4 € |
| 6810 | Roulement à billes à section mince 6810 2RS | 3 pce | 6 € | 18 € |
| 6802 | Roulement à billes 6802 2RS (came) | 6 pce | 1,5 € | 9 € |
| | **Sous-total roulements** | | | **71 €** |

### Goupilles

| Référence | Désignation | Quantité | Prix unitaire indicatif | Sous-total |
|---|---|---|---|---|
| Ø4×20 | Goupille cylindrique acier trempé ISO 8734 Ø4×20 mm | 115 pce | 0,08 € | 9,2 € |
| Ø4×24 | Goupille cylindrique acier trempé ISO 8734 Ø4×24 mm | 12 pce | 0,08 € | 0,96 € |
| Ø5×24 | Goupille cylindrique acier trempé ISO 8734 Ø5×24 mm | 39 pce | 0,12 € | 4,68 € |
| Ø3×20 | Goupille cylindrique acier trempé ISO 8734 Ø3×20 mm | 18 pce | 0,08 € | 1,44 € |
| | **Sous-total goupilles** | | | **16 €** |

### Structure

| Référence | Désignation | Quantité | Prix unitaire indicatif | Sous-total |
|---|---|---|---|---|
| Tube Ø40×2 L=117 | Tube rond aluminium 6060 Ø40×2 mm, à couper à 117 mm (ébavurer) | 1 pce | 6 € | 6 € |
| Tube Ø40×2 L=79 | Tube rond aluminium 6060 Ø40×2 mm, à couper à 79 mm (ébavurer) | 1 pce | 6 € | 6 € |
| | **Sous-total structure** | | | **12 €** |

### Pince

| Référence | Désignation | Quantité | Prix unitaire indicatif | Sous-total |
|---|---|---|---|---|
| MG996R | Servomoteur MG996R (couple 9–11 kg·cm, pignons métal) + palonnier rond | 1 pce | 7 € | 7 € |
| | **Sous-total pince** | | | **7 €** |

### Visserie

| Référence | Désignation | Quantité | Prix unitaire indicatif | Sous-total |
|---|---|---|---|---|
| M4×16 CHC | Vis CHC ISO 4762 M4×16 (fixation des modules) | 24 pce | 0,08 € | 1,92 € |
| M3×16 CHC | Vis CHC ISO 4762 M3×16 (interfaces de sortie) | 48 pce | 0,08 € | 3,84 € |
| M3×8 CHC | Vis CHC M3×8 (moteur NEMA17) | 20 pce | 0,05 € | 1 € |
| M5×16 CHC | Vis CHC M5×16 + écrou M5 (moteur NEMA23) | 4 pce | 0,12 € | 0,48 € |
| Écrou M5 | Écrou hexagonal M5 | 4 pce | 0,03 € | 0,12 € |
| M4×30 CHC | Vis CHC M4×30 + écrou (serrage des tubes) | 2 pce | 0,1 € | 0,2 € |
| Écrou M4 | Écrou hexagonal M4 | 2 pce | 0,03 € | 0,06 € |
| M3×50 CHC | Vis M3×50 + écrou nylstop (goupillage du tube d’avant-bras) | 2 pce | 0,15 € | 0,3 € |
| M4×12 CHC | Vis CHC M4×12 (plaque de base → socle) | 6 pce | 0,06 € | 0,36 € |
| M3×12 CHC | Vis CHC M3×12 (pince → bride J6) | 6 pce | 0,05 € | 0,3 € |
| M2×10 | Vis M2×10 + écrou (servo de pince, pignon) | 8 pce | 0,05 € | 0,4 € |
| M6 fixation | Vis M6 + rondelle (fixation à la table) | 4 pce | 0,2 € | 0,8 € |
| | **Sous-total visserie** | | | **10 €** |

### Inserts

| Référence | Désignation | Quantité | Prix unitaire indicatif | Sous-total |
|---|---|---|---|---|
| M4 insert | Insert fileté laiton à chaud M4 (L ≈ 6 mm) | 30 pce | 0,1 € | 3 € |
| M3 insert | Insert fileté laiton à chaud M3 (L ≈ 6 mm) | 48 pce | 0,1 € | 4,8 € |
| | **Sous-total inserts** | | | **8 €** |

### Consommables

| Référence | Désignation | Quantité | Prix unitaire indicatif | Sous-total |
|---|---|---|---|---|
| Colle frein | Frein filet faible (bleu) + graisse PTFE pour réducteurs | 1 lot | 8 € | 8 € |
| Époxy | Colle époxy bi-composant (tubes, cames) | 1 lot | 6 € | 6 € |
| Filament | Filament PETG ou PLA+ (≈ 2205 g de pièces + 25 % de marge/supports) | 2,8 kg | 22 € | 61,6 € |
| | **Sous-total consommables** | | | **76 €** |

### Électronique

| Référence | Désignation | Quantité | Prix unitaire indicatif | Sous-total |
|---|---|---|---|---|
| Teensy 4.1 | Microcontrôleur Teensy 4.1 (600 MHz, USB) | 1 pce | 35 € | 35 € |
| DM542T | Driver pas-à-pas numérique DM542T (20–50 V, 1–4,2 A) — ou TMC5160 / DM320T pour les petits axes | 6 pce | 22 € | 132 € |
| Alim 36 V | Alimentation 36 V 10 A (ex. Mean Well LRS-350-36) | 1 pce | 40 € | 40 € |
| Buck 6 V | Convertisseur abaisseur 36→6 V 5 A (servo de pince) | 1 pce | 6 € | 6 € |
| Buck 5 V | Convertisseur 36→5 V 3 A (Teensy, capteurs) | 1 pce | 4 € | 4 € |
| Capteur Hall | Capteur à effet Hall A3144 (sortie à collecteur ouvert) + aimant néodyme 6×3 mm | 6 pce | 1,5 € | 9 € |
| Arrêt d’urgence | Bouton champignon 22 mm à accrochage, 2 contacts NF (contacteur + entrée Teensy) | 1 pce | 10 € | 10 € |
| 74HCT245 | Tampon de niveaux 3,3 V → 5 V 74HCT245 (entrées optocouplées des drivers) | 2 pce | 1,5 € | 3 € |
| Relais | Contacteur/relais 12–36 V 20 A (coupure puissance moteurs par l’AU) | 1 pce | 10 € | 10 € |
| Câble 4G | Câble blindé 4×0,5 mm² (moteurs) — env. 8 m | 8 m | 1,2 € | 9,6 € |
| Câble 3G | Câble 3×0,25 mm² (capteurs, servo) — env. 8 m | 8 m | 0,6 € | 4,8 € |
| Connecteurs | Connecteurs GX16-4 (moteurs) + XT60 (puissance) + borniers | 1 lot | 18 € | 18 € |
| Fusible | Porte-fusible + fusible 10 A | 1 pce | 3 € | 3 € |
| | **Sous-total électronique** | | | **284 €** |

### Pièces imprimées

58 pièces (détail, orientation et réglages dans [7. Impression 3D](07-impression-3d.md)).

### Variante ORION-6 PRO (moteurs QDD en mode MIT)

La variante PRO remplace les six ensembles « moteur pas-à-pas + réducteur cycloïdal + driver » par des actionneurs
brushless à réducteur planétaire intégré pilotés en **mode MIT** sur bus CAN :

| Articulation | Actionneur | Couple crête / nominal | Remarque |
|---|---|---|---|
| J1, J2, J3 | Damiao **DM-J4340** (40:1) | 27 / 9 N·m | 24 V, codeur, driver intégré |
| J4, J5, J6 | Damiao **DM-J4310** (10:1) | 7 / 3 N·m | 24 V |
| Liaison | Teensy 4.1 + transceiver CAN 3,3 V (SN65HVD230 ou TJA1051T/3) | — | firmware `firmware/mit_bridge` |
| Puissance | Alimentation 24 V ≥ 15 A + arrêt d’urgence coupant la puissance | — | |

> Les brides d’adaptation imprimées pour ces moteurs ne sont **pas encore modélisées** : la CAO fournie est celle de la
> variante MAKER. La variante PRO est complète côté simulation, réglage (mode MIT) et firmware.

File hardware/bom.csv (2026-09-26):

Catégorie | Référence | Désignation | Quantité | Unité | Prix unitaire indicatif (€) | Note
Moteurs | NEMA17-48 | Moteur pas-à-pas NEMA17 48 mm, 1,8°/pas (ex. 0.59 N·m) | 1 | pce | 14.00
Roulements | 6811 | Roulement à billes à section mince 6811 2RS | 2 | pce | 8.00
Roulements | 6803 | Roulement à billes 6803 2RS (came) | 4 | pce | 1.60
Roulements | 688 | Roulement 688 2RS (8×16×5, support de came) | 6 | pce | 0.80
Goupilles | Ø4×20 | Goupille cylindrique acier trempé ISO 8734 Ø4×20 mm | 115 | pce | 0.08
Goupilles | Ø4×24 | Goupille cylindrique acier trempé ISO 8734 Ø4×24 mm | 12 | pce | 0.08
Moteurs | NEMA23-76 | Moteur pas-à-pas NEMA23 76 mm, 1,8°/pas (ex. 1.89 N·m) | 1 | pce | 32.00
Roulements | 6814 | Roulement à billes à section mince 6814 2RS | 1 | pce | 12.00
Roulements | 6804 | Roulement à billes 6804 2RS (came) | 2 | pce | 2.20
Goupilles | Ø5×24 | Goupille cylindrique acier trempé ISO 8734 Ø5×24 mm | 39 | pce | 0.12
Moteurs | NEMA17-60 | Moteur pas-à-pas NEMA17 60 mm, 1,8°/pas (ex. 0.65 N·m) | 1 | pce | 17.00
Moteurs | NEMA17-40 | Moteur pas-à-pas NEMA17 40 mm, 1,8°/pas (ex. 0.42 N·m) | 2 | pce | 12.00
Roulements | 6810 | Roulement à billes à section mince 6810 2RS | 3 | pce | 6.00
Roulements | 6802 | Roulement à billes 6802 2RS (came) | 6 | pce | 1.50
Goupilles | Ø3×20 | Goupille cylindrique acier trempé ISO 8734 Ø3×20 mm | 18 | pce | 0.08
Moteurs | NEMA17-34 | Moteur pas-à-pas NEMA17 34 mm, 1,8°/pas (ex. 0.28 N·m) | 1 | pce | 11.00
Structure | Tube Ø40×2 L=117 | Tube rond aluminium 6060 Ø40×2 mm, à couper à 117 mm (ébavurer) | 1 | pce | 6.00
Structure | Tube Ø40×2 L=79 | Tube rond aluminium 6060 Ø40×2 mm, à couper à 79 mm (ébavurer) | 1 | pce | 6.00
Pince | MG996R | Servomoteur MG996R (couple 9–11 kg·cm, pignons métal) + palonnier rond | 1 | pce | 7.00
Visserie | M4×16 CHC | Vis CHC ISO 4762 M4×16 (fixation des modules) | 24 | pce | 0.08
Inserts | M4 insert | Insert fileté laiton à chaud M4 (L ≈ 6 mm) | 30 | pce | 0.10
Visserie | M3×16 CHC | Vis CHC ISO 4762 M3×16 (interfaces de sortie) | 48 | pce | 0.08
Inserts | M3 insert | Insert fileté laiton à chaud M3 (L ≈ 6 mm) | 48 | pce | 0.10
Visserie | M3×8 CHC | Vis CHC M3×8 (moteur NEMA17) | 20 | pce | 0.05
Visserie | M5×16 CHC | Vis CHC M5×16 + écrou M5 (moteur NEMA23) | 4 | pce | 0.12
Visserie | Écrou M5 | Écrou hexagonal M5 | 4 | pce | 0.03
Visserie | M4×30 CHC | Vis CHC M4×30 + écrou (serrage des tubes) | 2 | pce | 0.10
Visserie | Écrou M4 | Écrou hexagonal M4 | 2 | pce | 0.03
Visserie | M3×50 CHC | Vis M3×50 + écrou nylstop (goupillage du tube d’avant-bras) | 2 | pce | 0.15
Visserie | M4×12 CHC | Vis CHC M4×12 (plaque de base → socle) | 6 | pce | 0.06
Visserie | M3×12 CHC | Vis CHC M3×12 (pince → bride J6) | 6 | pce | 0.05
Visserie | M2×10 | Vis M2×10 + écrou (servo de pince, pignon) | 8 | pce | 0.05
Visserie | M6 fixation | Vis M6 + rondelle (fixation à la table) | 4 | pce | 0.20
Consommables | Colle frein | Frein filet faible (bleu) + graisse PTFE pour réducteurs | 1 | lot | 8.00
Consommables | Époxy | Colle époxy bi-composant (tubes, cames) | 1 | lot | 6.00
Électronique | Teensy 4.1 | Microcontrôleur Teensy 4.1 (600 MHz, USB) | 1 | pce | 35.00
Électronique | DM542T | Driver pas-à-pas numérique DM542T (20–50 V, 1–4,2 A) — ou TMC5160 / DM320T pour les petits axes | 6 | pce | 22.00
Électronique | Alim 36 V | Alimentation 36 V 10 A (ex. Mean Well LRS-350-36) | 1 | pce | 40.00
Électronique | Buck 6 V | Convertisseur abaisseur 36→6 V 5 A (servo de pince) | 1 | pce | 6.00
Électronique | Buck 5 V | Convertisseur 36→5 V 3 A (Teensy, capteurs) | 1 | pce | 4.00
Électronique | Capteur Hall | Capteur à effet Hall A3144 (sortie à collecteur ouvert) + aimant néodyme 6×3 mm | 6 | pce | 1.50
Électronique | Arrêt d’urgence | Bouton champignon 22 mm à accrochage, 2 contacts NF (contacteur + entrée Teensy) | 1 | pce | 10.00
Électronique | 74HCT245 | Tampon de niveaux 3,3 V → 5 V 74HCT245 (entrées optocouplées des drivers) | 2 | pce | 1.50
Électronique | Relais | Contacteur/relais 12–36 V 20 A (coupure puissance moteurs par l’AU) | 1 | pce | 10.00
Électronique | Câble 4G | Câble blindé 4×0,5 mm² (moteurs) — env. 8 m | 8 | m | 1.20
Électronique | Câble 3G | Câble 3×0,25 mm² (capteurs, servo) — env. 8 m | 8 | m | 0.60
Électronique | Connecteurs | Connecteurs GX16-4 (moteurs) + XT60 (puissance) + borniers | 1 | lot | 18.00
Électronique | Fusible | Porte-fusible + fusible 10 A | 1 | pce | 3.00
Pièces imprimées | J1-housing | Carter CY-M | 1 | pce |  | PETG/PLA+ · remplissage 60 %
Pièces imprimées | J1-retainer | Couvercle CY-M | 1 | pce |  | PETG/PLA+ · remplissage 80 %
Pièces imprimées | J1-cam | Came excentrique CY-M | 1 | pce |  | PETG/PLA+ · remplissage 100 %
Pièces imprimées | J1-discA | Disque cycloïdal A CY-M | 1 | pce |  | PETG/PLA+ · remplissage 100 %
Pièces imprimées | J1-discB | Disque cycloïdal B CY-M | 1 | pce |  | PETG/PLA+ · remplissage 100 %
Pièces imprimées | J1-flange | Flasque de sortie CY-M | 1 | pce |  | PETG/PLA+ · remplissage 90 %
Pièces imprimées | J1-clamp | Bague de sortie CY-M | 1 | pce |  | PETG/PLA+ · remplissage 90 %
Pièces imprimées | J2-housing | Carter CY-L | 1 | pce |  | PETG/PLA+ · remplissage 60 %
Pièces imprimées | J2-retainer | Couvercle CY-L | 1 | pce |  | PETG/PLA+ · remplissage 80 %
Pièces imprimées | J2-cam | Came excentrique CY-L | 1 | pce |  | PETG/PLA+ · remplissage 100 %
Pièces imprimées | J2-discA | Disque cycloïdal A CY-L | 1 | pce |  | PETG/PLA+ · remplissage 100 %
Pièces imprimées | J2-discB | Disque cycloïdal B CY-L | 1 | pce |  | PETG/PLA+ · remplissage 100 %
Pièces imprimées | J2-flange | Flasque de sortie CY-L | 1 | pce |  | PETG/PLA+ · remplissage 90 %
Pièces imprimées | J2-clamp | Bague de sortie CY-L | 1 | pce |  | PETG/PLA+ · remplissage 90 %
Pièces imprimées | J3-housing | Carter CY-M | 1 | pce |  | PETG/PLA+ · remplissage 60 %
Pièces imprimées | J3-retainer | Couvercle CY-M | 1 | pce |  | PETG/PLA+ · remplissage 80 %
Pièces imprimées | J3-cam | Came excentrique CY-M | 1 | pce |  | PETG/PLA+ · remplissage 100 %
Pièces imprimées | J3-discA | Disque cycloïdal A CY-M | 1 | pce |  | PETG/PLA+ · remplissage 100 %
Pièces imprimées | J3-discB | Disque cycloïdal B CY-M | 1 | pce |  | PETG/PLA+ · remplissage 100 %
Pièces imprimées | J3-flange | Flasque de sortie CY-M | 1 | pce |  | PETG/PLA+ · remplissage 90 %
Pièces imprimées | J3-clamp | Bague de sortie CY-M | 1 | pce |  | PETG/PLA+ · remplissage 90 %
Pièces imprimées | J4-housing | Carter CY-S | 1 | pce |  | PETG/PLA+ · remplissage 60 %
Pièces imprimées | J4-retainer | Couvercle CY-S | 1 | pce |  | PETG/PLA+ · remplissage 80 %
Pièces imprimées | J4-cam | Came excentrique CY-S | 1 | pce |  | PETG/PLA+ · remplissage 100 %
Pièces imprimées | J4-discA | Disque cycloïdal A CY-S | 1 | pce |  | PETG/PLA+ · remplissage 100 %
Pièces imprimées | J4-discB | Disque cycloïdal B CY-S | 1 | pce |  | PETG/PLA+ · remplissage 100 %
Pièces imprimées | J4-flange | Flasque de sortie CY-S | 1 | pce |  | PETG/PLA+ · remplissage 90 %
Pièces imprimées | J4-clamp | Bague de sortie CY-S | 1 | pce |  | PETG/PLA+ · remplissage 90 %
Pièces imprimées | J5-housing | Carter CY-S | 1 | pce |  | PETG/PLA+ · remplissage 60 %
Pièces imprimées | J5-retainer | Couvercle CY-S | 1 | pce |  | PETG/PLA+ · remplissage 80 %
Pièces imprimées | J5-cam | Came excentrique CY-S | 1 | pce |  | PETG/PLA+ · remplissage 100 %
Pièces imprimées | J5-discA | Disque cycloïdal A CY-S | 1 | pce |  | PETG/PLA+ · remplissage 100 %
Pièces imprimées | J5-discB | Disque cycloïdal B CY-S | 1 | pce |  | PETG/PLA+ · remplissage 100 %
Pièces imprimées | J5-flange | Flasque de sortie CY-S | 1 | pce |  | PETG/PLA+ · remplissage 90 %
Pièces imprimées | J5-clamp | Bague de sortie CY-S | 1 | pce |  | PETG/PLA+ · remplissage 90 %
Pièces imprimées | J6-housing | Carter CY-S | 1 | pce |  | PETG/PLA+ · remplissage 60 %
Pièces imprimées | J6-retainer | Couvercle CY-S | 1 | pce |  | PETG/PLA+ · remplissage 80 %
Pièces imprimées | J6-cam | Came excentrique CY-S | 1 | pce |  | PETG/PLA+ · remplissage 100 %
Pièces imprimées | J6-discA | Disque cycloïdal A CY-S | 1 | pce |  | PETG/PLA+ · remplissage 100 %
Pièces imprimées | J6-discB | Disque cycloïdal B CY-S | 1 | pce |  | PETG/PLA+ · remplissage 100 %
Pièces imprimées | J6-flange | Flasque de sortie CY-S | 1 | pce |  | PETG/PLA+ · remplissage 90 %
Pièces imprimées | J6-clamp | Bague de sortie CY-S | 1 | pce |  | PETG/PLA+ · remplissage 90 %
Pièces imprimées | base-plate | Plaque de base | 1 | pce |  | PETG/PLA+ · remplissage 50 %
Pièces imprimées | socle | Socle (fût) | 1 | pce |  | PETG/PLA+ · remplissage 40 %
Pièces imprimées | turret | Tourelle (tambour d’épaule) | 1 | pce |  | PETG/PLA+ · remplissage 45 %
Pièces imprimées | upperarm-low | Raccord bas du bras | 1 | pce |  | PETG/PLA+ · remplissage 60 %
Pièces imprimées | upperarm-high | Raccord haut du bras (porte J3) | 1 | pce |  | PETG/PLA+ · remplissage 60 %
Pièces imprimées | elbow | Bloc coude (porte J4) | 1 | pce |  | PETG/PLA+ · remplissage 45 %
Pièces imprimées | forearm-adapter | Adaptateur de tube (sortie J4) | 1 | pce |  | PETG/PLA+ · remplissage 60 %
Pièces imprimées | wrist | Poignet (porte J5) | 1 | pce |  | PETG/PLA+ · remplissage 55 %
Pièces imprimées | yoke | Chape (J5 → J6) | 1 | pce |  | PETG/PLA+ · remplissage 70 %
Pièces imprimées | gripper-body | Corps de pince | 1 | pce |  | PETG/PLA+ · remplissage 50 %
Pièces imprimées | gripper-pinion | Pignon m1 z20 | 1 | pce |  | PETG/PLA+ · remplissage 100 %
Pièces imprimées | gripper-finger-left | Doigt gauche (crémaillère m1) | 1 | pce |  | PETG/PLA+ · remplissage 80 %
Pièces imprimées | gripper-pad-left | Patin gauche (TPU) | 1 | pce |  | TPU · remplissage 100 %
Pièces imprimées | gripper-finger-right | Doigt droit (crémaillère m1) | 1 | pce |  | PETG/PLA+ · remplissage 80 %
Pièces imprimées | gripper-pad-right | Patin droit (TPU) | 1 | pce |  | TPU · remplissage 100 %
Pièces imprimées | tolerance-test | Test de tolérances | 1 | pce |  | PETG/PLA+ · remplissage 100 %
Consommables | Filament | Filament PETG ou PLA+ (≈ 2205 g de pièces + 25 % de marge/supports) | 2.8 | kg | 22.00

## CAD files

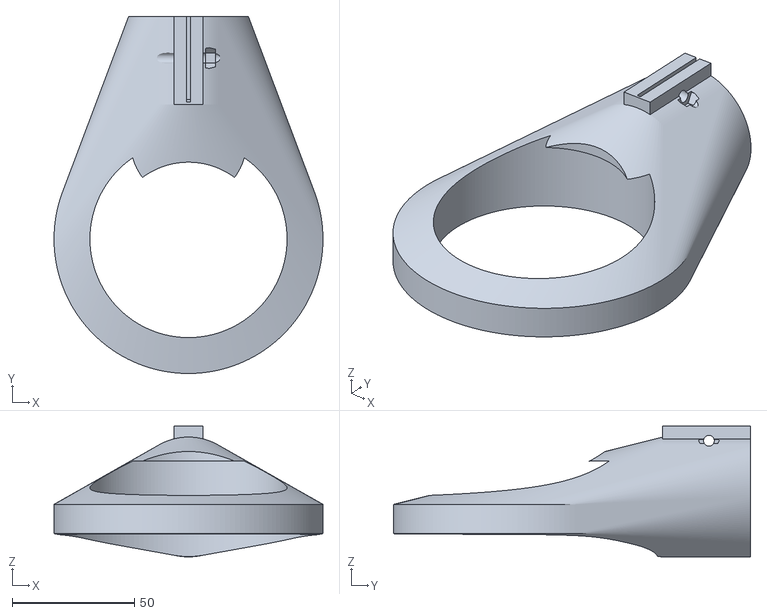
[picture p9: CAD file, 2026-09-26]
hardware/stl/upperarm-high.stl
110.0 x 146.0 x 53.5

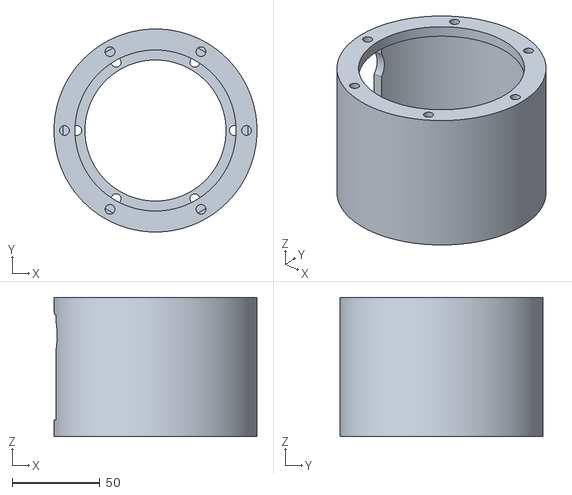
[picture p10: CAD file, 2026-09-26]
hardware/stl/socle.stl
116.0 x 116.0 x 79.7

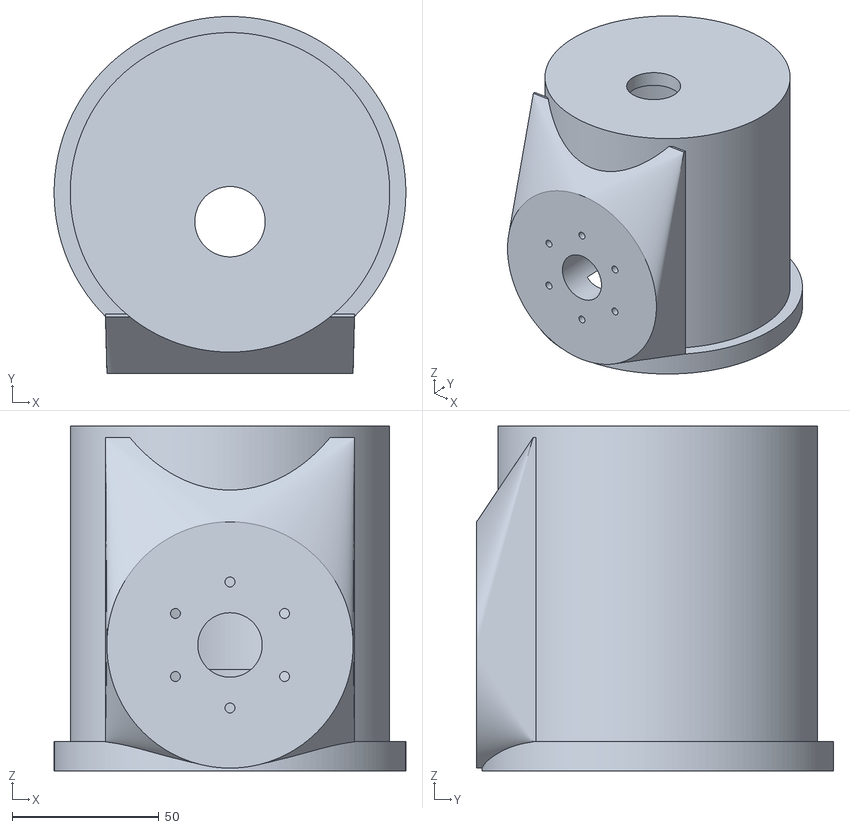
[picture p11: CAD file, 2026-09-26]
hardware/stl/turret.stl
120.0 x 121.8 x 117.7

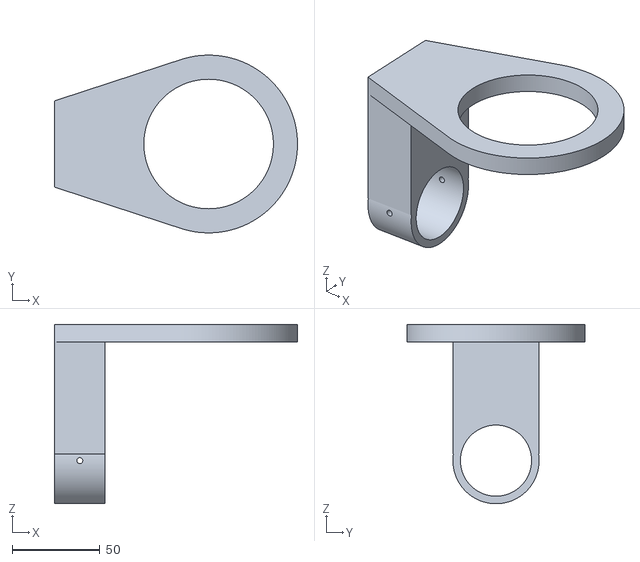
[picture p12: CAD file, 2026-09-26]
hardware/stl/wrist.stl
138.1 x 101.0 x 102.0

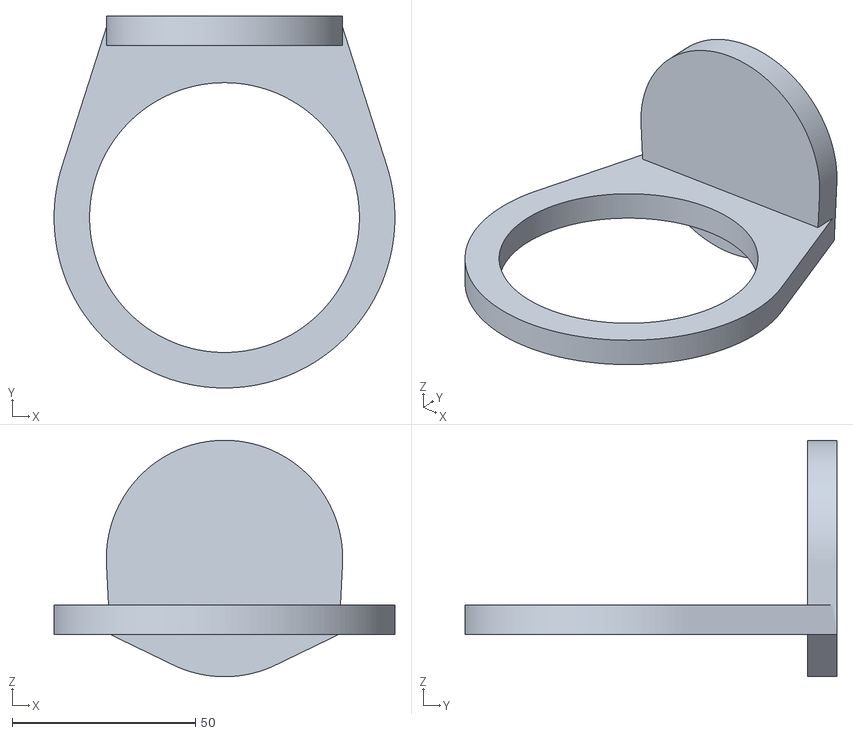
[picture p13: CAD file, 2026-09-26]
hardware/stl/yoke.stl
93.0 x 101.5 x 64.5

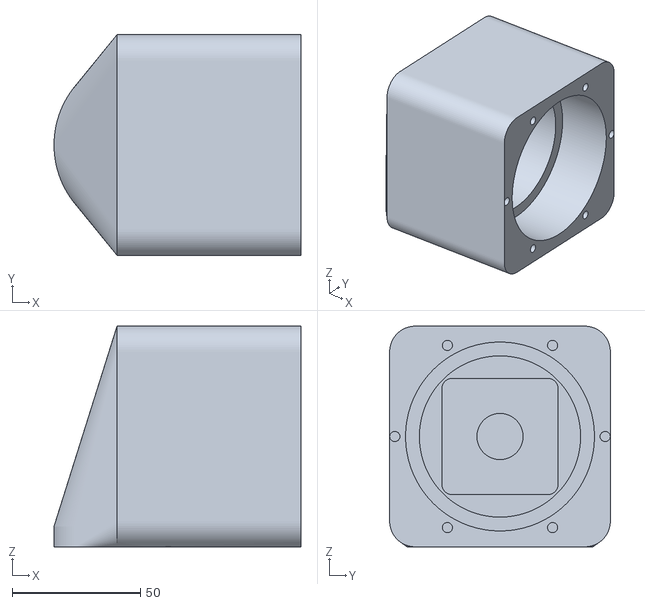
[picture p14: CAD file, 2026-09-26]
hardware/stl/elbow.stl
96.2 x 86.0 x 86.0

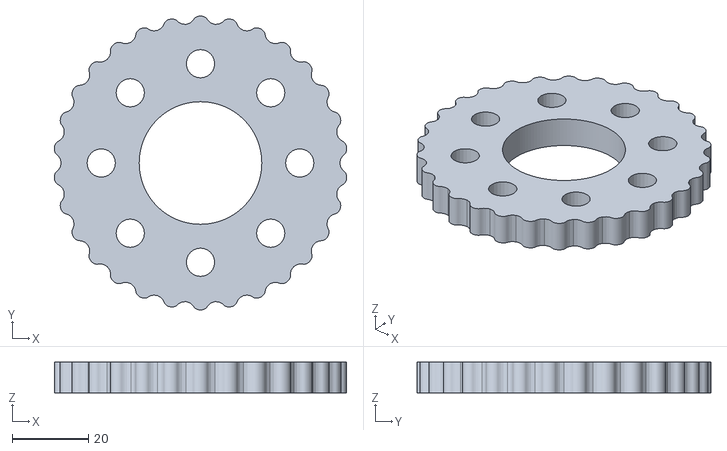
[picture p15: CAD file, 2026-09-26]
hardware/stl/CY-L_discA.stl
76.6 x 77.0 x 8.00

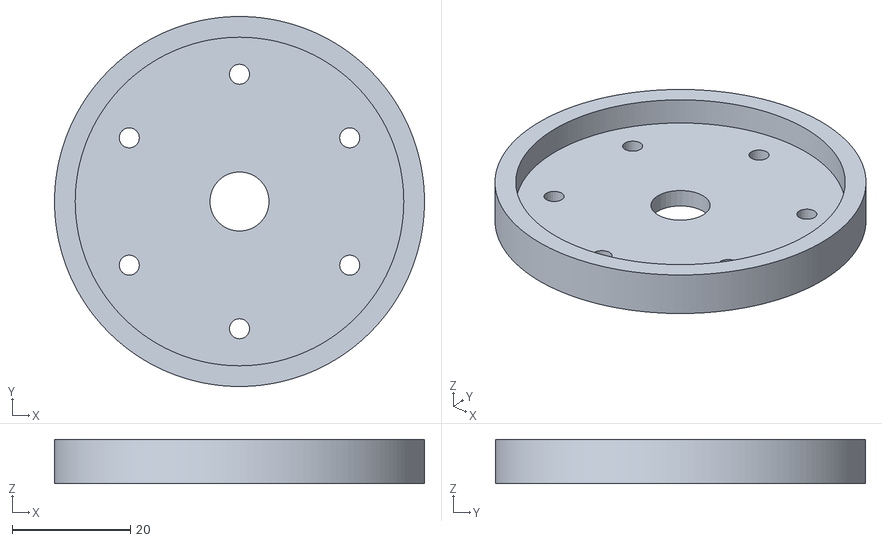
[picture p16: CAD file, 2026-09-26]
hardware/stl/CY-M_clamp.stl
62.5 x 62.5 x 7.50

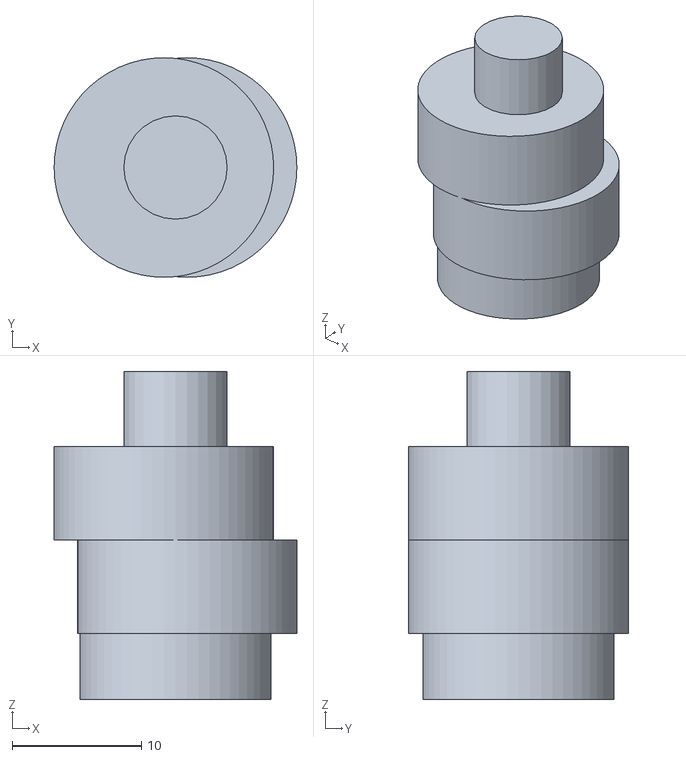
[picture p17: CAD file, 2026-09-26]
hardware/stl/CY-M_cam.stl
18.8 x 17.0 x 25.4

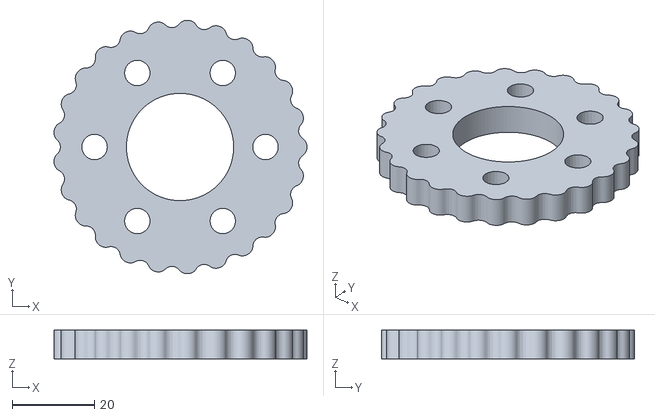
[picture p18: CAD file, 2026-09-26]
hardware/stl/CY-M_discB.stl
61.6 x 61.7 x 7.00

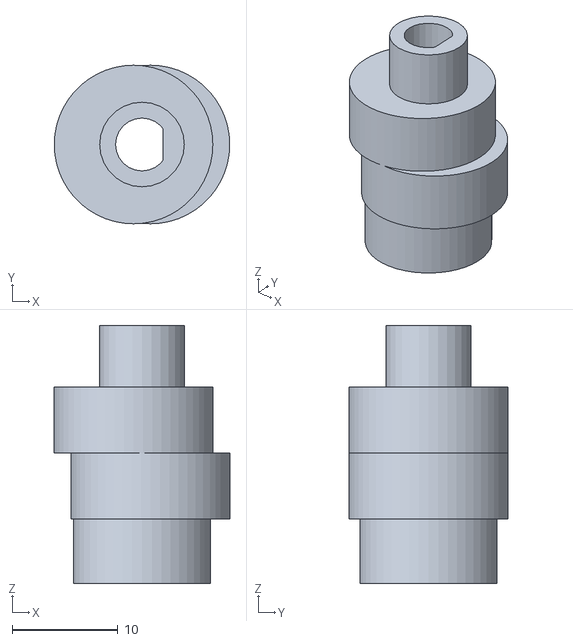
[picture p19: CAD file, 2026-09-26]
hardware/stl/CY-S_cam.stl
16.6 x 15.0 x 24.4

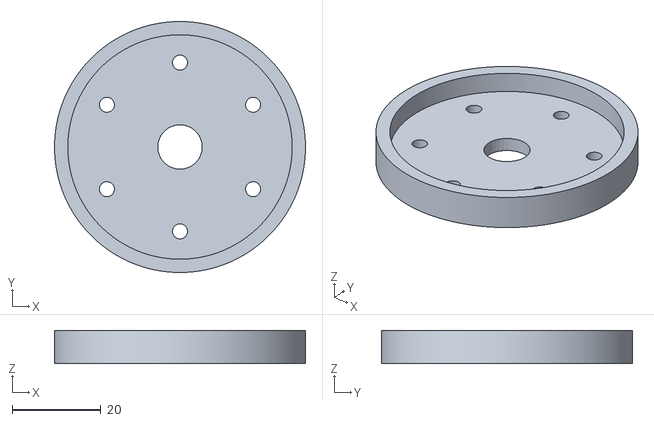
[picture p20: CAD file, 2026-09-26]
hardware/stl/CY-S_clamp.stl
56.5 x 56.5 x 7.50

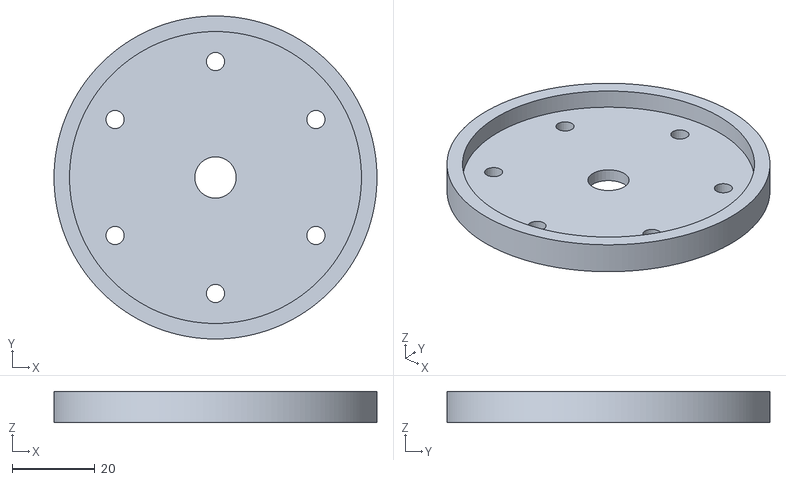
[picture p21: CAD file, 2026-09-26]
hardware/stl/CY-L_clamp.stl
78.0 x 78.0 x 7.50

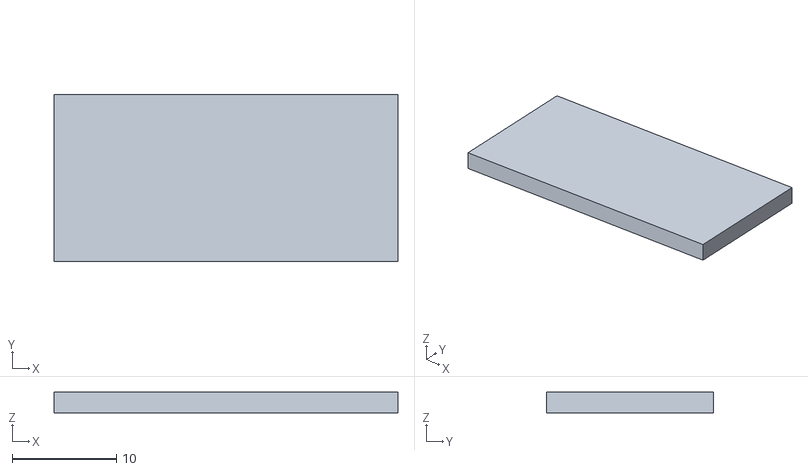
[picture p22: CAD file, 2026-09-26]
hardware/stl/gripper-pad-right.stl
33.0 x 16.0 x 2.00

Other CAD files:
hardware/stl/CY-L_housing.stl
hardware/stl/CY-S_retainer.stl
hardware/stl/CY-M_retainer.stl
hardware/stl/CY-L_retainer.stl
hardware/stl/CY-L_cam.stl
hardware/stl/CY-L_discB.stl
hardware/stl/CY-L_flange.stl
hardware/stl/CY-M_discA.stl
hardware/stl/CY-M_flange.stl
hardware/stl/CY-M_housing.stl
hardware/stl/CY-S_discA.stl
hardware/stl/CY-S_discB.stl
hardware/stl/CY-S_flange.stl
hardware/stl/CY-S_housing.stl
hardware/stl/base-plate.stl
hardware/stl/forearm-adapter.stl
hardware/stl/gripper-body.stl
hardware/stl/gripper-finger-left.stl
hardware/stl/gripper-finger-right.stl
hardware/stl/gripper-pad-left.stl
hardware/stl/gripper-pinion.stl
hardware/stl/tolerance-test.stl
hardware/stl/upperarm-low.stl

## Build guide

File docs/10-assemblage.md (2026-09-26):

# 10. Assemblage

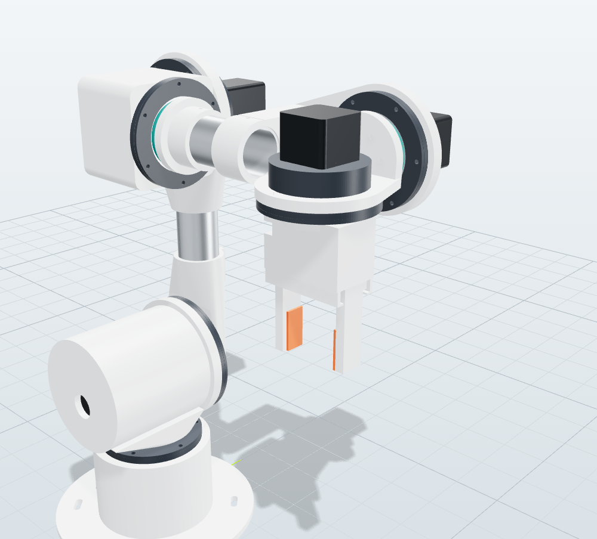
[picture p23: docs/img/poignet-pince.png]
Poignet et pince


> Ce guide suit la CAO du dépôt. La géométrie a été contrôlée (0 interférence, débattements vérifiés), mais le montage
> n’a **pas encore été réalisé** sur un exemplaire physique. Signalez toute difficulté pour faire évoluer la CAO.
> Dans ORION Studio, l’onglet *Pièces 3D* met chaque pièce en évidence dans la vue 3D : gardez-le ouvert pendant le
> montage.

## Outillage

- Fer à souder avec panne pour inserts (ou panne conique), réglé à 230–245 °C pour le PETG.
- Clés Allen 2 / 2,5 / 3 / 4 mm, pied à coulisse, cutter d’ébavurage, lime douce.
- Étau (ou petite presse) pour emmancher goupilles et roulements, avec cales en bois.
- Scie à métaux + boîte à onglets, ou coupe-tube, pour les tubes aluminium. Lime et ébavureur.
- Frein filet faible (bleu), graisse PTFE (réducteurs), colle époxy bi-composant.

Serrages : les vis dans les inserts se serrent **à la main**, soit environ 0,6 N·m en M3 et 1,2 N·m en M4. Trop serrées,
elles arrachent l’insert du plastique.

## Étape 0 : préparation

1. Imprimez et validez `tolerance-test.stl` (voir [7. Impression 3D](07-impression-3d.md)).
2. Ébavurez toutes les pièces : pied d’éléphant, fils, bavures dans les alésages. Passez un foret à la main dans les
   trous de goupilles s’ils sont trop serrés.
3. **Posez tous les inserts filetés** avant tout assemblage : pointe du fer dans l’insert, pression douce et
   perpendiculaire. Arrêtez à fleur, puis appuyez une pièce plane dessus pendant le refroidissement.
4. Coupez les tubes Ø40 × 2 aux longueurs de la nomenclature : **117 mm** pour le bras, **79 mm** pour l’avant-bras.
   Coupes d’équerre, ébavurées.

## Étape 1 : les six modules réducteurs cycloïdaux

Six modules sont à monter : **CY-M** pour J1 et J3, **CY-L** pour J2, **CY-S** pour J4, J5 et J6. Ils sont tous
construits de la même façon :

```
   moteur ─┬─ carter (galets) ─ disque A ─ disque B ─ roulement principal ─ flasque (+ doigts, 688) ─ bague de sortie
           └─ came (2 roulements) sur l’arbre moteur
```

| Module | Galets (couronne) | Disques | Roulement principal | Came | Doigts de sortie |
|---|---|---|---|---|---|
| CY-S (20:1) | 21 × Ø4 × 20 | 20 lobes, e = 0,8 mm | 6810 | 2 × 6802 | 6 × Ø3 × 20 |
| CY-M (25:1) | 26 × Ø4 × 20 | 25 lobes, e = 0,9 mm | 6811 | 2 × 6803 | 6 × Ø4 × 24 |
| CY-L (30:1) | 31 × Ø5 × 24 | 30 lobes, e = 1,0 mm | 6814 | 2 × 6804 | 8 × Ø5 × 24 |

1. **Galets** : enfoncez les goupilles dans les trous du fond du carter, avec une cale et de légers coups ou à l’étau.
   Elles doivent être **parallèles** et tenir seules. Contrôlez-en une sur deux avec une équerre.
2. **Moteur** : fixez-le au dos du carter (NEMA17 : 4 × M3 × 8 ; NEMA23 : 4 × M5 × 16 + écrous). L’arbre traverse le
   fond.
3. **Came** : emmanchez les deux roulements de came sur les deux excentriques. Enfilez ensuite la came sur l’arbre
   moteur, **méplat contre méplat**, avec une goutte de frein filet, et poussez-la jusqu’en butée.
4. **Disque A** : enfilez-le sur le roulement de came inférieur en le tournant doucement pour engrener ses lobes entre
   les galets.
5. **Disque B**, repéré au marqueur : enfilez-le sur le roulement supérieur. Il est décalé d’un demi-lobe, donc il
   s’engrène naturellement quand la came est orientée à 180°. **Ne permutez jamais A et B.**
6. **Graissage** : une fine couche de graisse PTFE sur les galets et les trous de doigts. Pas de graisse épaisse, qui
   freine à basse température.
7. **Flasque de sortie** : emmanchez les doigts (goupilles de sortie) et le roulement 688 au centre, puis présentez le
   flasque. Les doigts entrent dans les trous des disques et le bout de la came dans le 688.
8. **Roulement principal** : emmanchez-le sur le flasque puis dans le logement avant du carter. Posez le **couvercle**
   (bague extérieure) puis la **bague de sortie** (bague intérieure), vissée dans les inserts du flasque.
9. **Essai à la main** : tournez l’arbre moteur (ou la sortie, beaucoup plus dur). La rotation doit être régulière, sans
   point dur sur un tour complet de sortie.
   - La sortie tourne **en sens inverse** du moteur : c’est normal pour une cycloïde, le logiciel le gère par le sens
     de l’axe.
   - Jeu à la sortie : il doit être à peine perceptible (≤ 0,3°). En cas de point dur, cherchez un pied d’éléphant sur
     un disque ou un galet mal enfoncé.

## Étape 2 : base et J1

1. **Plaque de base → socle** : 6 × M4 × 12 dans les inserts du socle. Orientez l’ouverture de passage des câbles
   de la plaque vers le boîtier électronique.
2. **Module J1 (CY-M)** : moteur vers le bas, à l’intérieur du socle. Fixez-le par le couvercle sur les inserts M4 de
   la face supérieure du socle (6 × M4 × 16).
3. Fixez le robot sur la table (4 × vis M6 dans les lumières). Un bras qui accélère exerce plusieurs N·m de
   basculement : **ne le faites jamais fonctionner posé libre**.

## Étape 3 : épaule (J2)

1. **Tourelle** : vissez-la sur la bague de sortie de J1 (6 × M3 × 16).
2. **Module J2 (CY-L)** : glissez le moteur NEMA23 dans l’alésage horizontal de la tourelle, puis fixez le module par
   son couvercle (6 × M4 × 16).

## Étape 4 : bras (J2 → J3)

1. **Raccord bas** (`upperarm-low`) sur la sortie de J2 (6 × M4 × 16).
2. **Tube de 117 mm** : engagez-le dans le raccord bas et le raccord haut (`upperarm-high`). Avant de serrer les vis
   M4 × 30 + écrous des colliers :
   - **alignez les axes** J2 et J3 (parallèles, contrôle à la règle sur les faces des modules) ;
   - réglez l’**entraxe J2–J3 à 240 mm** (paramètre DH a₂), au pied à coulisse d’axe à axe. La différence mesurée peut
     être saisie dans *Paramètres → Cinématique → a*.
3. **Module J3 (CY-M, NEMA17 60 mm)** dans le raccord haut, moteur côté extérieur (6 × M4 × 16).

## Étape 5 : coude et avant-bras (J3 → J4 → poignet)

1. **Bloc coude** (`elbow`) sur la sortie de J3. Il loge le module **J4 (CY-S)**, moteur vers l’arrière.
2. **Adaptateur de tube** (`forearm-adapter`) sur la sortie de J4.
3. **Tube de 79 mm** : collez-le à l’époxy dans l’adaptateur et dans le logement du poignet. Percez Ø3,2 et goupillez
   chaque extrémité avec une vis M3 × 50 + écrou nylstop.
   - Avant la prise de la colle, contrôlez la **distance axe J3 ↔ axe J5 = 220 mm** (d₄) et l’alignement de J5
     perpendiculaire à J4.

## Étape 6 : poignet (J5, J6)

1. **Module J5 (CY-S)** dans le poignet, moteur dépassant côté +y.
2. **Chape** (`yoke`) sur la sortie de J5.
3. **Module J6 (CY-S, NEMA17 34 mm)** : son carter se fixe sur la chape. La bague de sortie de J6 est la **bride
   outil**.

## Étape 7 : pince

1. Mettez le servo **au milieu de sa course** (1 500 µs, par exemple avec `GRIP 50` une fois le firmware en place, ou un
   testeur de servo).
2. Glissez le servo MG996R par le dessous du corps de pince et fixez-le (4 × M2).
3. Placez les deux doigts dans leurs glissières, **ouverts de la même valeur**. Engagez le **pignon** (vissé sur le
   palonnier rond, 4 × M2) entre les deux crémaillères, puis vissez-le sur l’axe du servo.
4. Collez les patins TPU sur les doigts.
5. Vissez le corps de pince sur la bride J6 (6 × M3 × 12). Vérifiez que `GRIP 0` ferme sans forcer contre la butée
   (réglez sinon `SET grip_closed`) et que `GRIP 100` ouvre à 50 mm.

## Étape 8 : capteurs et câblage

1. **Aimants et capteurs Hall** : collez l’aimant sur la partie tournante et le capteur sur la partie fixe, pour que le
   capteur soit atteint environ 2° au-delà de la butée logicielle (J1 −172°, J2 −133°, J3 +62°, J4 −172°, J5 −117°,
   J6 −182°). L’angle exact se mesure ensuite par calibration ([12. Calibration](12-calibration.md)).
2. **Câbles** :
   - regroupez les câbles de chaque segment dans une gaine tressée ;
   - fixez-les avec des colliers aux raccords imprimés ;
   - laissez une **boucle de service** autour de chaque articulation, dimensionnée pour son débattement complet
     (J1, J4 et J6 tournent de près de 360°).
   - Tous les câbles redescendent par l’ouverture de la plaque de base vers le boîtier électronique.
3. **Test de débattement, moteurs non alimentés** : amenez chaque axe à la main d’une butée à l’autre (doucement, à
   travers la réduction). Aucun câble ne doit se tendre ni frotter.

## Étape 9 : contrôle final avant mise sous tension

- [ ] Toutes les vis serrées, les modules tournent librement à la main.
- [ ] Bras fixé à la table, zone dégagée dans un rayon de 80 cm.
- [ ] Arrêt d’urgence câblé **et testé** (coupe la puissance des moteurs).
- [ ] Capteurs testés un par un (voir [9. Électronique](09-electronique.md), mise sous tension).
- [ ] Paramètres envoyés (`Envoyer la config`), vitesse réduite à 10–25 %.

Suite : [12. Calibration et mise en service](12-calibration.md).

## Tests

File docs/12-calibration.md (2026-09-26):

# 12. Calibration et mise en service

La calibration fait coïncider le **modèle** (ORION Studio, firmware) avec **votre** robot : sens des axes, échelles,
zéros, longueurs, masses. Travaillez à **vitesse réduite** (10–25 %), l’arrêt d’urgence à portée de main.

Outils utiles :

- inclinomètre numérique (ou application de téléphone calibrée) ;
- pied à coulisse ;
- comparateur à cadran sur support magnétique ;
- balance de cuisine ;
- rapporteur.

## 1. Sens de rotation (axes non référencés)

Moteurs actifs (`EN 1`), sans prise d’origine, déplacez chaque axe de +5° :

```
JG 1 5      JG 2 5      JG 3 5      JG 4 5      JG 5 5      JG 6 5
```

| Axe | Sens positif attendu |
|---|---|
| J1 | rotation anti-horaire vue de dessus |
| J2 | le bras penche vers l’avant (+X) |
| J3 | l’avant-bras s’abaisse |
| J4 | rotation anti-horaire autour de l’avant-bras, vue depuis le poignet en regardant vers le coude |
| J5 | l’outil s’incline vers le bas (depuis la pose Zéro) |
| J6 | rotation anti-horaire autour de l’axe de l’outil, vue depuis le bout des doigts en regardant vers le poignet |

Un axe tourne à l’envers ? Deux corrections possibles :

- `SET invert n 1` puis `SAVE` ;
- cocher *Inverser DIR* dans ORION Studio, puis *Envoyer la config*.

En cas de doute, activez les *Repères DH* dans la vue 3D : l’axe z de chaque repère donne le sens positif (règle de la
main droite).

## 2. Échelle (pas par degré)

Pour chaque axe, repérez un trait sur la partie fixe et la partie mobile, puis commandez un grand déplacement, par
exemple `JG 1 30` trois fois (90°). Mesurez l’angle réel au rapporteur ou à l’inclinomètre.

steps_per_deg_nouveau = steps_per_deg_actuel × angle_commandé / angle_mesuré

Un écart d’un facteur 2 ou 4 signale un mauvais réglage des micro-pas du driver. Un écart de 4 % sur un CY-M (26/25)
signale une confusion entre nombre de galets et rapport de réduction. Corrigez la cause plutôt que la valeur.

## 3. Positions des capteurs d’origine

Après `HOME`, le firmware croit être en `home_pose`. L’écart réel vient de la position exacte du capteur. Pour chaque
axe :

1. `HOME`, puis `MJ 0 …` vers une pose où l’axe est mesurable :
   - J2 et J3 : bras vertical, avant-bras horizontal (pose *Zéro*), vérifiés à l’inclinomètre ;
   - J1 : bras dans l’axe X de la table (repère tracé) ;
   - J4, J5, J6 : faces planes du poignet et de la pince, à l’équerre.
2. Mesurez l’écart δ = angle réel − angle commandé, avec le signe du sens positif de l’axe.
3. Corrigez : `SET home_pos n (home_pos + δ)`, puis `SAVE`. Recommencez `HOME` et vérifiez.

Exemple : après `HOME` puis `MJ 0 0 0 0 0 90 0`, l’inclinomètre sur le tube du bras indique 1,2° vers l’avant
(J2 réel = +1,2°). Faites `SET home_pos 2 -131.8` (−133 + 1,2), `SAVE`, puis `HOME`.

**Répétabilité de la prise d’origine** : enchaînez 5 `HOME` et mesurez la pose Home au comparateur (TCP contre une
cale). La dispersion doit rester sous 0,1 mm. Sinon, réduisez `home_slow` et vérifiez la fixation de l’aimant et du
capteur.

## 4. Géométrie (table DH) et outil

- **Longueurs** : mesurez d’axe à axe a₂ (J2 → J3, nominal 240 mm) et d₄ (J3 → centre du poignet, nominal 220 mm).
  Reportez-les dans *Paramètres → Cinématique*.
  - ⚠️ Modifier a₂ ou d₄ **régénère aussi la CAO**, avec d’autres longueurs de tube. Pour une simple correction après
    montage, c’est sans conséquence : n’imprimez rien de nouveau.
- **Outil (TCP)** : mesurez la distance bride → bout des doigts fermés (nominal 100,3 mm), et reportez-la dans *TCP —
  Z*. Pour un autre outil (stylo, ventouse), renseignez aussi X/Y et l’orientation.
- **Vérification** : placez une pointe fixe sur la table. Amenez le TCP dessus dans trois configurations différentes
  (MoveL avec orientations différentes). Si la pointe « tourne » autour du TCP, la longueur d’outil ou les zéros J4–J6
  sont faux.

## 5. Masses (dynamique, compensation de gravité)

Pesez les sous-ensembles au montage : bras, coude avec avant-bras, poignet, pince. Corrigez les masses dans *Paramètres
→ Dynamique*. Les centres de masse calculés par la CAO restent de bonnes valeurs de départ.

- **Pas-à-pas** : les masses servent au dimensionnement (*Analyse*) et aux anticipations de la simulation.
- **PRO (mode MIT)** : elles déterminent directement la **compensation de gravité**. Vérifiez-les en mode *Compensation
  de gravité* :
  - le bras lâché dans une pose quelconque doit rester en place, ou dériver lentement ;
  - s’il retombe, augmentez la masse (ou le centre de masse) du segment concerné ;
  - s’il remonte, diminuez-la.

## 6. Raideur et jeu des réducteurs (pour la simulation)

Pour chaque axe, moteur actif et à l’arrêt :

1. Placez un comparateur sur le segment à une distance r de l’axe (par exemple 100 mm).
2. Appliquez à la main un effort alterné, faible puis plus fort, avec un peson à la distance r si possible.
3. **Jeu** : la zone où le comparateur bouge sans effort donne jeu (rad) = course / r.
4. **Raideur** : la pente au-delà du jeu donne k = (F·r) / (déplacement / r) en N·m/rad.

Reportez jeu et raideur dans *Paramètres → Actionneurs*. Le simulateur, l’auto-réglage des gains et le choix de la zone
morte les utilisent.

## 7. Pince

- `GRIP 0` : les doigts doivent se toucher **sans forcer**. Le servo ne doit ni grogner ni chauffer. Ajustez
  `SET grip_closed * 950` (valeur en µs), puis `SAVE`.
- `GRIP 100` : ouverture maximale sans butée dure (`SET grip_open * …`).

## 8. ORION-6 PRO : moteurs, zéros et gains

1. **Chaque moteur, seul sur le bus**, avec l’outil du fabricant :
   - mode **MIT** ;
   - identifiant CAN = numéro d’axe (1 à 6) ;
   - identifiant maître ;
   - plages **P_MAX = 12,5 rad**, **V_MAX** (8 rad/s pour DM4340, 30 rad/s pour DM4310), **T_MAX** (28 N·m pour
     DM4340, 10 N·m pour DM4310).

   Ces plages doivent être identiques à celles d’ORION Studio (*Actionneurs*).
2. **Bus complet** : `STREAM 10` puis `FB`. Les six moteurs doivent répondre (températures plausibles, erreur `1` =
   actif ou `0` = inactif).
3. **Sens** : moteurs coupés, tournez chaque axe à la main dans son sens positif (tableau §1). La valeur de `STAT` doit
   croître ; sinon, `SET dir n -1`.
4. **Zéro** : posez le bras dans sa **pose de repos** sur un support (J2 −10°, J3 55°, J5 35°, les autres à 0), puis
   `ZERO` et `SAVE`. Contrôlez ensuite `STAT` dans deux ou trois poses mesurées à l’inclinomètre.
   - Les moteurs à réducteur intégré ne connaissent leur position absolue qu’à l’intérieur d’un tour moteur. Après
     une coupure d’alimentation, vérifiez donc toujours `STAT` **avant** `EN 1`. Si la position est fausse, reposez le
     bras en pose de repos et refaites `ZERO`.
5. **Gains** : suivez [6. Commande et réglage](06-commande-et-reglage.md#6-réglage-spécifique-orion-6-pro-mode-mit).
   Commencez avec la moitié des gains par défaut, **compensation de gravité active**.

## 9. Validation finale

1. Programme **Test de répétabilité** (exemple d’ORION Studio) en *Jumeau numérique*, avec un comparateur au point
   d’arrivée. Relevez la dispersion sur 20 cycles.
2. Programme **Prise et dépose** avec un vrai cube de 30 mm aux positions indiquées.
3. Montée en vitesse progressive : 25, puis 50, puis 75 % en surveillant :
   - l’absence de pas perdus : la position après `HOME` doit rester identique ;
   - les températures des moteurs ;
   - le bruit des réducteurs.
4. Sauvegardez la configuration validée : *Paramètres → JSON* (fichier) et `SAVE` (EEPROM).

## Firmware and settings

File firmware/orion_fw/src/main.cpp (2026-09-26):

// ORION-6 firmware — cible Teensy 4.1 (Arduino/Teensyduino ou PlatformIO).
//
//  • Interruption 100 kHz (IntervalTimer) : génération des impulsions STEP (Robot::stepIsr)
//  • Boucle principale : lecture USB, anti-rebond des capteurs, tick 1 kHz (Robot::tick1ms)
//
// Le brochage et les paramètres par défaut viennent de orion_config.h, généré par
// ORION Studio (Exporter → Configuration firmware) ou par `npm run build:firmware-config`.
#include <Arduino.h>
#include <EEPROM.h>

#include "core/robot.h"

using namespace orion;

namespace {

// Entrées/sorties TOR libres (non utilisées par les axes)
constexpr uint8_t DI_PINS[8] = {16, 17, 18, 19, 20, 21, 22, 23};
constexpr uint8_t DO_PINS[8] = {31, 32, 34, 35, 36, 37, 38, 39};
constexpr uint8_t LED_PIN = 13;

class TeensyHal : public Hal {
 public:
  void begin() {
    for (int a = 0; a < NA; a++) {
      pinMode(orion_cfg::STEP_PIN[a], OUTPUT);
      pinMode(orion_cfg::DIR_PIN[a], OUTPUT);
      digitalWriteFast(orion_cfg::STEP_PIN[a], LOW);
      pinMode(orion_cfg::LIMIT_PIN[a], orion_cfg::LIMIT_ACTIVE_LOW[a] ? INPUT_PULLUP : INPUT_PULLDOWN);
    }
    pinMode(orion_cfg::ENABLE_PIN, OUTPUT);
    enableDrivers(false);
    // Arrêt d’urgence : contact NF vers GND → niveau haut = arrêt (fil coupé compris)
    pinMode(orion_cfg::ESTOP_PIN, INPUT_PULLUP);
    for (uint8_t p : DI_PINS) pinMode(p, INPUT_PULLUP);
    for (uint8_t p : DO_PINS) { pinMode(p, OUTPUT); digitalWriteFast(p, LOW); }
    pinMode(LED_PIN, OUTPUT);
    // Servo de pince : MLI matérielle 50 Hz, résolution 16 bits (≈ 0,3 µs)
    analogWriteResolution(16);
    analogWriteFrequency(orion_cfg::GRIPPER_PIN, 50);
  }

  // Anti-rebond : un capteur doit être stable 2 ms pour changer d’état
  void poll() {
    for (int a = 0; a < NA; a++) {
      const bool raw = digitalReadFast(orion_cfg::LIMIT_PIN[a]) == (orion_cfg::LIMIT_ACTIVE_LOW[a] ? LOW : HIGH);
      filt(limitCnt_[a], limit_[a], raw);
    }
    filt(estopCnt_, estop_, digitalReadFast(orion_cfg::ESTOP_PIN) == HIGH);
  }

  void stepHigh(uint8_t a) override { digitalWriteFast(orion_cfg::STEP_PIN[a], HIGH); }
  void stepLow(uint8_t a) override { digitalWriteFast(orion_cfg::STEP_PIN[a], LOW); }
  void setDir(uint8_t a, bool positive) override { digitalWriteFast(orion_cfg::DIR_PIN[a], positive ? HIGH : LOW); }
  void enableDrivers(bool on) override {
    digitalWriteFast(orion_cfg::ENABLE_PIN, (on != orion_cfg::ENABLE_ACTIVE_LOW) ? HIGH : LOW);
  }
  bool limitActive(uint8_t a) override { return limit_[a]; }
  bool estopActive() override { return estop_; }
  void setGripperUs(uint16_t us) override {
    analogWrite(orion_cfg::GRIPPER_PIN, (uint32_t)us * 65535UL / 20000UL);
  }
  void setOutput(uint8_t n, bool v) override {
    if (n < 8) digitalWriteFast(DO_PINS[n], v ? HIGH : LOW);
  }
  bool readInput(uint8_t n) override { return n < 8 && digitalReadFast(DI_PINS[n]) == LOW; }
  void write(const char* line) override {
    const size_t n = strlen(line);
    // Jamais bloquant : si l’hôte ne lit pas, la ligne est abandonnée
    if (Serial.dtr() && Serial.availableForWrite() >= (int)n) Serial.write(line, n);
  }
  bool saveBlob(const void* data, uint32_t len) override {
    const uint8_t* p = static_cast<const uint8_t*>(data);
    for (uint32_t i = 0; i < len; i++) EEPROM.update(i, p[i]);
    return true;
  }
  bool loadBlob(void* data, uint32_t len) override {
    uint8_t* p = static_cast<uint8_t*>(data);
    for (uint32_t i = 0; i < len; i++) p[i] = EEPROM.read(i);
    return true;
  }
  void irqLock(bool lock) override {
    // noInterrupts()/interrupts() sont des macros : accolades obligatoires
    if (lock) {
      noInterrupts();
    } else {
      interrupts();
    }
  }

 private:
  static void filt(uint8_t& cnt, bool& state, bool raw) {
    if (raw == state) { cnt = 0; return; }
    if (++cnt >= 2) { state = raw; cnt = 0; }
  }
  bool limit_[NA] = {false};
  uint8_t limitCnt_[NA] = {0};
  bool estop_ = true;  // prudence au démarrage : levé tant que l’entrée n’est pas lue
  uint8_t estopCnt_ = 0;
};

TeensyHal hal;
Robot robot(hal);
IntervalTimer stepTimer;
uint32_t lastTickUs = 0;

void stepIsr() { robot.stepIsr(); }

void updateLed() {
  // Rythme de la LED : lente = prêt, rapide = mouvement, fixe = défaut / arrêt d’urgence
  const uint32_t t = robot.millis();
  bool on;
  switch (robot.state()) {
    case State::FAULT:
    case State::ESTOP: on = true; break;
    case State::RUN:
    case State::HOMING: on = (t / 100) & 1; break;
    case State::IDLE: on = (t % 2000) < 50; break;
    default: on = (t / 500) & 1; break;
  }
  digitalWriteFast(LED_PIN, on ? HIGH : LOW);
}

}  // namespace

void setup() {
  Serial.begin(115200);  // USB natif : la vitesse est ignorée
  hal.begin();
  for (int i = 0; i < 3; i++) hal.poll();
  robot.begin();
  stepTimer.priority(32);  // priorité haute (0 = maximale), au-dessus de l’USB
  stepTimer.begin(stepIsr, 1000000.0f / ISR_HZ);
  lastTickUs = micros();
}

void loop() {
  while (Serial.available() > 0) robot.onChar((char)Serial.read());
  // Tick 1 kHz cadencé sur micros() (rattrapage si la boucle a pris du retard)
  uint32_t guard = 0;
  while ((uint32_t)(micros() - lastTickUs) >= 1000 && guard++ < 10) {
    lastTickUs += 1000;
    hal.poll();
    robot.tick1ms();
  }
  if (guard >= 10) lastTickUs = micros();
  updateLed();
}

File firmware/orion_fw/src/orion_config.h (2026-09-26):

// FICHIER GÉNÉRÉ par ORION Studio (Exporter → Configuration firmware).
// Robot : ORION-6
// Toutes les valeurs angulaires sont en DEGRÉS côté articulation (sortie de réducteur).
#pragma once
#include <stdint.h>

#define ORION_NUM_AXES 6
#define ORION_ROBOT_NAME "ORION-6"

namespace orion_cfg {
// Pas moteur par degré articulaire = (360/angle_pas) × micro-pas × réduction / 360
constexpr float STEPS_PER_DEG[ORION_NUM_AXES] = { 222.22222, 266.66667, 222.22222, 177.77778, 177.77778, 177.77778 };
constexpr float MIN_DEG[ORION_NUM_AXES]       = { -170.000, -130.000, -170.000, -170.000, -115.000, -180.000 };
constexpr float MAX_DEG[ORION_NUM_AXES]       = { 170.000, 130.000, 60.000, 170.000, 115.000, 180.000 };
constexpr float VMAX_DEG_S[ORION_NUM_AXES]    = { 120.000, 90.000, 110.000, 170.000, 170.000, 200.000 };
constexpr float AMAX_DEG_S2[ORION_NUM_AXES]   = { 300.000, 200.000, 300.000, 600.000, 600.000, 700.000 };
constexpr uint8_t STEP_PIN[ORION_NUM_AXES]    = { 2, 4, 6, 8, 10, 12 };
constexpr uint8_t DIR_PIN[ORION_NUM_AXES]     = { 3, 5, 7, 9, 11, 14 };
constexpr uint8_t LIMIT_PIN[ORION_NUM_AXES]   = { 24, 25, 26, 27, 28, 29 };
constexpr bool INVERT_DIR[ORION_NUM_AXES]     = { false, false, false, false, false, false };
constexpr bool LIMIT_ACTIVE_LOW[ORION_NUM_AXES] = { true, true, true, true, true, true };
constexpr bool HOMING_ENABLED[ORION_NUM_AXES] = { true, true, true, true, true, true };
constexpr int8_t HOMING_DIR[ORION_NUM_AXES]   = { -1, -1, 1, -1, -1, -1 };
constexpr float HOMING_SPEED[ORION_NUM_AXES]  = { 20.000, 15.000, 15.000, 30.000, 30.000, 30.000 };
constexpr float HOMING_SLOW[ORION_NUM_AXES]   = { 2.000, 2.000, 2.000, 3.000, 3.000, 3.000 };
constexpr float HOMING_BACKOFF[ORION_NUM_AXES] = { 4.000, 4.000, 4.000, 5.000, 5.000, 5.000 };
constexpr float HOMING_SWITCH_POS[ORION_NUM_AXES] = { -172.000, -133.000, 62.000, -172.000, -117.000, -182.000 };
constexpr uint8_t HOMING_ORDER[ORION_NUM_AXES] = { 4, 5, 3, 2, 1, 0 };
constexpr float HOME_POSE_DEG[ORION_NUM_AXES] = { 0.000, 0.000, 0.000, 0.000, 90.000, 0.000 };
constexpr uint8_t ENABLE_PIN = 15;
constexpr bool ENABLE_ACTIVE_LOW = true;
constexpr uint8_t ESTOP_PIN = 30;
constexpr uint8_t GRIPPER_PIN = 33;
constexpr uint16_t GRIPPER_US_CLOSED = 900;
constexpr uint16_t GRIPPER_US_OPEN = 2100;
constexpr float STEP_PULSE_US = 3.00f;
constexpr float DIR_SETUP_US = 6.00f;
constexpr uint32_t WATCHDOG_MS = 250;
constexpr uint32_t CAN_BITRATE = 1000000;
// Mode MIT (pont CAN) : identifiants et plages des moteurs
constexpr uint8_t CAN_ID[ORION_NUM_AXES] = { 1, 2, 3, 4, 5, 6 };
constexpr float MIT_PMAX[ORION_NUM_AXES] = { 12.500, 12.500, 12.500, 12.500, 12.500, 12.500 };
constexpr float MIT_VMAX[ORION_NUM_AXES] = { 8.000, 8.000, 8.000, 8.000, 8.000, 8.000 };
constexpr float MIT_TMAX[ORION_NUM_AXES] = { 28.000, 28.000, 28.000, 28.000, 28.000, 28.000 };
constexpr float MIT_KPMAX[ORION_NUM_AXES] = { 500.000, 500.000, 500.000, 500.000, 500.000, 500.000 };
constexpr float MIT_KDMAX[ORION_NUM_AXES] = { 5.000, 5.000, 5.000, 5.000, 5.000, 5.000 };
constexpr float MIT_KP[ORION_NUM_AXES] = { 90.000, 130.000, 90.000, 30.000, 30.000, 15.000 };
constexpr float MIT_KD[ORION_NUM_AXES] = { 3.0000, 4.0000, 2.5000, 1.0000, 1.0000, 0.5000 };
constexpr float MIT_KD_DAMP[ORION_NUM_AXES] = { 5.0000, 5.0000, 5.0000, 2.0000, 2.0000, 1.0000 };
constexpr int8_t MIT_DIR[ORION_NUM_AXES] = { 1, 1, 1, 1, 1, 1 };
constexpr float TAU_MAX[ORION_NUM_AXES] = { 10.320, 39.690, 11.380, 5.880, 5.880, 3.920 };  // N·m
constexpr float REF_POSE_DEG[ORION_NUM_AXES] = { 0.000, -10.000, 55.000, 0.000, 35.000, 0.000 };  // pose de référence (ZERO)
constexpr uint16_t MIT_CTRL_HZ = 400;
constexpr uint16_t MIT_FB_TIMEOUT_MS = 50;
constexpr uint8_t MIT_MAX_TEMP_C = 85;
constexpr uint16_t STREAM_DELAY_MS = 40;
}  // namespace orion_cfg

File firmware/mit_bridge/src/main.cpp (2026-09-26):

// ORION-6 PRO — pont USB ↔ CAN « mode MIT », cible Teensy 4.1.
//
// Câblage : CAN1 (broche 22 = CTX1, 23 = CRX1) → transceiver 3,3 V (SN65HVD230, TJA1051T/3…)
// → bus CAN_H/CAN_L des moteurs (DM4340/DM4310), terminaison 120 Ω aux deux extrémités.
// Arrêt d’urgence : contact NF vers GND sur ESTOP_PIN (la coupure de puissance reste matérielle).
#include <Arduino.h>
#include <EEPROM.h>
#include <FlexCAN_T4.h>

#include "mit_core.h"

namespace {

FlexCAN_T4<CAN1, RX_SIZE_256, TX_SIZE_64> can1;
constexpr uint8_t LED_PIN = 13;

class TeensyBridgeHal : public mit::BridgeHal {
 public:
  void begin() {
    pinMode(orion_cfg::ESTOP_PIN, INPUT_PULLUP);
    pinMode(LED_PIN, OUTPUT);
    can1.begin();
    can1.setBaudRate(orion_cfg::CAN_BITRATE);
    can1.setMaxMB(16);
    can1.enableFIFO();
  }
  void poll() {
    const bool raw = digitalReadFast(orion_cfg::ESTOP_PIN) == HIGH;
    if (raw == estop_) cnt_ = 0;
    else if (++cnt_ >= 2) { estop_ = raw; cnt_ = 0; }
  }
  bool canSend(uint32_t id, const uint8_t d[8]) override {
    CAN_message_t m;
    m.id = id;
    m.len = 8;
    m.flags.extended = 0;
    memcpy(m.buf, d, 8);
    return can1.write(m) != 0;
  }
  bool canReceive(uint32_t& id, uint8_t d[8]) override {
    CAN_message_t m;
    if (!can1.read(m)) return false;
    id = m.id;
    memcpy(d, m.buf, 8);
    return true;
  }
  void write(const char* line) override {
    const size_t n = strlen(line);
    if (Serial.dtr() && Serial.availableForWrite() >= (int)n) Serial.write(line, n);
  }
  bool estopActive() override { return estop_; }
  bool saveBlob(const void* data, uint32_t len) override {
    const uint8_t* p = static_cast<const uint8_t*>(data);
    for (uint32_t i = 0; i < len; i++) EEPROM.update(i, p[i]);
    return true;
  }
  bool loadBlob(void* data, uint32_t len) override {
    uint8_t* p = static_cast<uint8_t*>(data);
    for (uint32_t i = 0; i < len; i++) p[i] = EEPROM.read(i);
    return true;
  }

 private:
  bool estop_ = true;
  uint8_t cnt_ = 0;
};

TeensyBridgeHal hal;
mit::Bridge bridge(hal);
uint32_t lastTickUs = 0;

}  // namespace

void setup() {
  Serial.begin(115200);
  hal.begin();
  for (int i = 0; i < 3; i++) hal.poll();
  bridge.begin();
  lastTickUs = micros();
}

void loop() {
  can1.events();  // vide la file d’émission CAN
  while (Serial.available() > 0) bridge.onChar((char)Serial.read());
  uint32_t guard = 0;
  while ((uint32_t)(micros() - lastTickUs) >= 1000 && guard++ < 10) {
    lastTickUs += 1000;
    hal.poll();
    bridge.tick1ms();
  }
  if (guard >= 10) lastTickUs = micros();
  const mit::State s = bridge.state();
  const uint32_t t = bridge.millis();
  const bool on = (s == mit::State::FAULT || s == mit::State::ESTOP) ? true
                  : (s == mit::State::RUN) ? ((t / 100) & 1)
                  : (s == mit::State::IDLE) ? ((t % 2000) < 50)
                  : ((t / 500) & 1);
  digitalWriteFast(LED_PIN, on ? HIGH : LOW);
}

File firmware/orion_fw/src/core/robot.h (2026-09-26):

// ORION-6 firmware — cœur portable : protocole ORION-ASCII, génération de mouvement,
// prise d’origine, sécurité. Aucune dépendance Arduino.
//
// Deux cadences :
//   • tick1ms()  : boucle 1 kHz (consignes, prise d’origine, sécurité, calcul des vitesses de pas)
//   • stepIsr()  : interruption 100 kHz (accumulateur DDA → impulsions STEP régulières)
#pragma once
#include <stdint.h>
#include "hal.h"
#include "../orion_config.h"

namespace orion {

constexpr int NA = ORION_NUM_AXES;
constexpr uint32_t ISR_HZ = 100000;
constexpr uint32_t ISR_PER_MS = ISR_HZ / 1000;
constexpr const char* FW_VERSION = "1.0.0";

enum class State : uint8_t { IDLE, READY, HOMING, RUN, HOLD, FAULT, ESTOP };
const char* stateName(State s);

// Bits du champ « flags » de la ligne ST (identiques à studio/core/protocol.js)
enum Flag : uint32_t {
  F_ENABLED = 0x01, F_HOMED = 0x02, F_MOVING = 0x04, F_FAULT = 0x08, F_ESTOP_IN = 0x10,
  F_WATCHDOG = 0x20, F_LIMIT = 0x40, F_UNDERRUN = 0x80, F_LIMITED = 0x100,
};

// Configuration modifiable (SET/GET) et sauvegardée en EEPROM
struct Config {
  uint32_t magic;
  uint16_t version;
  uint16_t size;
  float stepsPerDeg[NA];
  float minDeg[NA], maxDeg[NA];
  float vmax[NA], amax[NA];
  uint8_t invert[NA];
  int8_t homeDir[NA];
  float homePos[NA], homeSpeed[NA], homeSlow[NA], homeBackoff[NA];
  float homePose[NA];
  uint8_t homeOrder[NA];
  uint8_t homeEnabled[NA];
  uint16_t watchdogMs;
  uint16_t streamDelayMs;  // retard du tampon de lissage des consignes SP
  uint16_t gripClosedUs, gripOpenUs;
  uint32_t crc;
};

void defaultConfig(Config& c);
uint32_t crc32(const uint8_t* d, uint32_t n);
bool configValid(const Config& c);

class Robot {
 public:
  explicit Robot(Hal& hal);
  void begin();
  void tick1ms();            // à appeler toutes les 1 ms
  void stepIsr();            // à appeler à ISR_HZ
  void onChar(char c);       // octets reçus sur l’USB
  void handleLine(char* line);

  // Accès (tests / diagnostic)
  State state() const { return state_; }
  bool homed() const { return homed_; }
  bool enabled() const { return enabled_; }
  int32_t stepPos(int a) const { return pos_[a]; }
  float posDeg(int a) const { return (float)pos_[a] / cfg_.stepsPerDeg[a]; }
  float desDeg(int a) const { return pDes_[a] / cfg_.stepsPerDeg[a]; }
  float velDeg(int a) const { return vDes_[a] * 1000.f / cfg_.stepsPerDeg[a]; }  // °/s
  Config& config() { return cfg_; }
  uint32_t millis() const { return now_; }
  uint32_t flags() const;

 private:
  enum class Motion : uint8_t { NONE, MOVEJ, STREAM, STOPPING, HOMING };
  enum class HStep : uint8_t { START, CLEAR, FAST, BACK, SLOW, RELEASE };

  struct SpPoint {
    float t;       // horodatage émetteur (ms, déroulé)
    float q[NA];   // pas
    float v[NA];   // pas/ms
    bool hasVel;
  };

  void reply(const char* fmt, ...);
  void sendStatus();
  void setState(State s);
  void fault(const char* why);
  void enable(bool on);
  void setPosition(int a, int32_t steps);
  bool parseFloats(char** tok, int n, float* out);
  void cmdMoveJ(float T, const float* qDeg, bool checkLimits);
  void cmdStream(uint32_t seq16, uint32_t t16, const float* qDeg, const float* vDeg);
  void cmdStop();
  void cmdHome(uint32_t mask);
  void cmdSet(const char* key, const char* axis, float v);
  void cmdGet(const char* key, const char* axis);
  float* cfgField(const char* key, uint8_t*& u8, int8_t*& i8);
  void motionTick();
  bool streamTarget(float* target);
  void homingTick();
  void computeRates();
  void clampToLimits(float* p) const;
  void beginMotion(Motion m);
  float degToSteps(int a, float deg) const { return deg * cfg_.stepsPerDeg[a]; }

  Hal& hal_;
  Config cfg_;
  State state_ = State::IDLE;
  Motion motion_ = Motion::NONE;
  bool homed_ = false;
  bool enabled_ = false;
  uint32_t now_ = 0;
  char faultMsg_[48] = {0};

  // Position réelle (pas émis) et consigne (pas, flottant)
  volatile int32_t pos_[NA] = {0};
  float pDes_[NA] = {0};
  float vDes_[NA] = {0};         // pas/ms
  float lastTarget_[NA] = {0};   // cible du tick précédent (anticipation de vitesse)
  volatile float rate_[NA] = {0};  // pas par tick ISR (signé)
  volatile float phase_[NA] = {0};
  volatile int8_t dir_[NA] = {0};     // sens appliqué (broche DIR)
  volatile int8_t dirReq_[NA] = {0};  // sens demandé par la boucle 1 kHz
  volatile uint8_t dirHold_[NA] = {0};
  volatile uint8_t pulseHigh_[NA] = {0};

  // MoveJ synchronisé (trapèze 25/50/25)
  float mjStart_[NA] = {0}, mjDelta_[NA] = {0};
  uint32_t mjT0_ = 0, mjDur_ = 0;

  // Flux de consignes SP : tampon de lissage horodaté
  static constexpr int SPN = 32;
  SpPoint sp_[SPN];
  uint32_t spW_ = 0, spR_ = 0;          // compteurs écriture / segment courant
  uint32_t spLastSeq_ = 0;
  uint16_t spLastT16_ = 0;              // dernier horodatage reçu (16 bits, ms)
  float spClock_ = 0;                   // horloge de lecture (temps émetteur, ms)
  float spLagF_ = 0;                    // avance du tampon, filtrée (ms)
  uint32_t spLastArrival_ = 0;
  bool spStarted_ = false;
  bool underrun_ = false, limited_ = false, watchdogTrip_ = false;

  // Prise d’origine
  uint32_t homeMask_ = 0;
  int homeIdx_ = 0;
  HStep hstep_ = HStep::START;
  float htravel_ = 0;

  // Divers
  uint16_t statusHz_ = 0;
  uint32_t nextStatus_ = 0;
  char line_[200];
  uint8_t lineLen_ = 0;
  bool lineOverflow_ = false;
  bool out_[8] = {false};
};

}  // namespace orion

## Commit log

2026-09-26 Cœur ORION-6 : schéma de paramètres, cinématique, dynamique, actionneurs, commande, trajectoires, simulateur, langage ORL et assistant NL
    - Schéma unique de ~175 paramètres (FR, unités, bornes, aides)
    - FK/jacobien DH standard et modifiée, IK analytique 8 solutions + IK numérique LM
    - Newton-Euler récursif, matrice d'inertie, dynamique directe
    - Modèles pas-à-pas (couple-angle, perte de pas), QDD mode MIT, jeu, frottements
    - Correcteurs : pas-à-pas, PID, MIT, couple calculé, impédance, compensation de gravité
    - Profils en S / trapèze / quintique / cycloïdal, MoveJ/MoveL/MoveC avec lissage
    - Simulateur semi-implicite (articulations flexibles), collisions capsules
    - Langage d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
2026-09-26 ORION Studio : interface web (vue 3D, pilotage, programme ORL, assistant IA, paramètres, analyse, courbes, robot réel)
    - Vue Three.js Z-haut : gizmo TCP avec IK temps réel, fantôme, trace, repères DH, capsules, poussée Maj+glisser
    - Pilotage articulaire/cartésien (jog maintenu, suivi servo), 8 solutions IK, pince, E/S, cubes à saisir
    - Éditeur ORL coloré avec ligne courante, exemples, mémorisation de points
    - Assistant langage naturel FR/EN avec dictée vocale
    - Éditeur de ~175 paramètres généré depuis le schéma, exports JSON/URDF/MJCF/firmware
    - Analyse : dimensionnement moteurs, charge utile max, réponse indicielle, auto-réglage, efforts roulements
    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
2026-09-26 CAO paramétrique ORION-6 : modules cycloïdaux imprimés, structure, pince, STL, nomenclature et contrôles
    - Modules d'articulation CY-S/M/L (20:1, 25:1, 30:1) : carter à gorges de galets, came excentrique,
    2 disques déphasés d'un demi-lobe (engrènement vérifié numériquement), flasque, bague de sortie
    - Structure : socle, tourelle-tambour (NEMA23 logé), bras en tube alu Ø40 + raccords serrés,
    bloc coude, avant-bras, poignet, chape, pince pignon/crémaillères (servo MG996R)
    - 37 STL orientés pour l'impression (hardware/stl), nomenclature CSV, parts.json
    - Masses/inerties réelles et capsules de collision générées vers le modèle dynamique
    - Contrôles : interférences sta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
    [CY-L_cam.stl, CY-L_clamp.stl, CY-L_discA.stl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]
2026-09-26 Firmware Teensy 4.1 : contrôleur pas-à-pas et pont CAN mode MIT
    - orion_fw : cœur portable (protocole ORION-ASCII à somme de contrôle,
    MoveJ trapézoïdal synchronisé, flux SP horodaté avec tampon de lissage
    et interpolation d'Hermite, limiteur vitesse/accélération sans
    dépassement, prise d'origine avec dégagement, butées, chien de garde,
    arrêt d'urgence, SET/GET/SAVE en EEPROM), génération de pas DDA 100 kHz
    avec délais DIR/STEP garantis, couche matérielle Teensy
    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
    [bom.csv, elbow.stl, socle.stl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]
2026-09-26 Documentation (début), version autonome ORION-Studio.html, J3 en NEMA17-60
    - tools/build-app.mjs : ORION Studio en un seul fichier HTML hors ligne
    (JS regroupé, CSS et moteur CAO WebAssembly intégrés) → dist/
    - Documentation française : README, présentation, guide du logiciel,
    cinématique, dynamique, commande et réglage ; pages générées depuis le
    schéma et la CAO (179 paramètres, impression 3D, nomenclature chiffrée)
    - Images de documentation (captures du logiciel, rendus du bras)
    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
    [bom.csv, upperarm-high.stl]
2026-09-26 Documentation complète : électronique, assemblage, firmware, calibration, dépannage, sources
    - docs/09 à 14 : câblage Teensy/drivers/arrêt d'urgence/CAN, montage des
    réducteurs et de la structure, référence du protocole ORION-ASCII et du
    pont MIT (exemple Python), calibration pas à pas, dépannage, sources
    - Aide intégrée : parcours « Robot réel » mis à jour
    - build-cad : sortie reproductible (plus de durée dans parts.json)
    - Coût matériel mis à jour (≈ 581 €)
    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
